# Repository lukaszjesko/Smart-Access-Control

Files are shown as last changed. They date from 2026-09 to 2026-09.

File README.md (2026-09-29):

# Smart Access Control — RFID + PIN Door Lock

Two-factor access control terminal on a custom PCB. Verification combines
something you **have** (a 13.56 MHz contactless card) with something you
**know** (a 4-digit PIN), driving an electric strike through a relay.

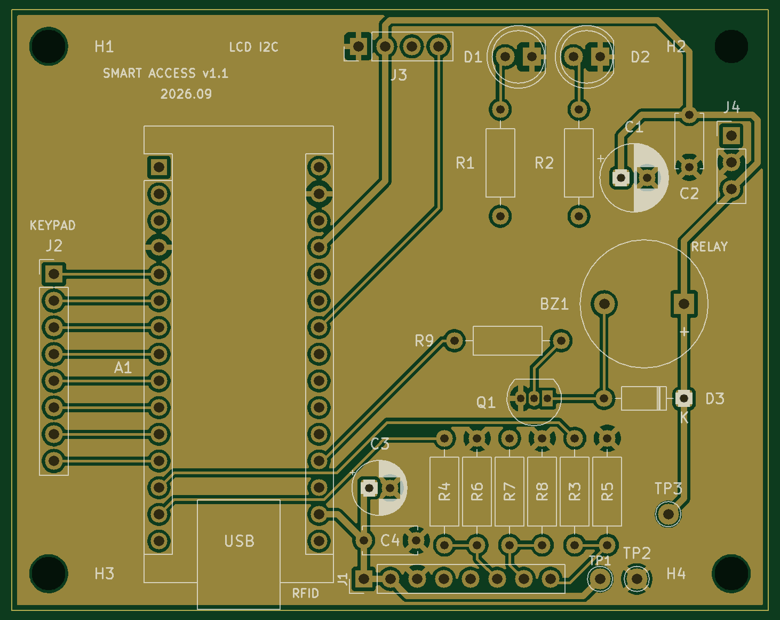
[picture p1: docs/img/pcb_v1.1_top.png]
PCB v1.1, top side


*PCB v1.1 rendered from the fabrication Gerbers. A photo of the assembled board replaces it after bring-up.*

---

## Status

| Stage | State |
|---|---|
| Firmware | Working on a breadboard |
| Schematic v1.1 | Complete, ERC clean |
| PCB v1.1 | 2-layer, 72 × 57 mm, all 28 nets routed, DRC clean |
| Fabrication | **v1.1 ordered 29 Sep 2026** (JLCPCB, 5 pcs) — files in [`fab/v1.1`](Zamek_RFID_Hardware/fab/v1.1) |
| Assembly and bring-up | Pending — boards expected mid-October |

v1.0 was never manufactured: a design review found blocking errors first.
[What the review caught](#what-the-v10-review-caught--fixed-in-v11) is the part
of this repository I would point a reviewer to first.

---

## Why this project

I wanted one device that forced me through the full hardware workflow rather
than a breadboard demo: requirements, schematic capture, footprint assignment,
layout, design rule check, manufacturing output, assembly, and bring-up.
Access control was chosen because its failure modes are interesting — a lock
that fails open is a security problem, and a lock that fails closed is a
safety problem.

---

## How it works

```
        ┌──────────────┐  SPI   ┌─────────────┐
        │  MFRC522     │◄──────►│             │
        │  RFID reader │        │             │
        └──────────────┘        │             │
                                │  ATmega328P │  GPIO   ┌────────────┐  12 V
        ┌──────────────┐  GPIO  │  (Nano)     │────────►│   Relay    │───────►
        │  4×4 keypad  │◄──────►│             │         │            │  strike
        └──────────────┘        │             │         └────────────┘
                                │             │
        ┌──────────────┐  I2C   │             │  GPIO   ┌────────────┐
        │  LCD 16×2    │◄──────►│             │────────►│ LEDs, buzz │
        └──────────────┘        └─────────────┘         └────────────┘
```

The firmware is a finite state machine with five states:

```
WAIT_FOR_CARD ──card matches──► WAIT_FOR_PIN ──► ENTERING_PIN
      ▲                                                │
      │                                    ┌───────────┴───────────┐
      │                                    ▼                       ▼
      └────────────────────────────── GRANTED                  DENIED
```

Access requires **both** factors. A valid card alone does not unlock the door.

---

## Hardware

### Pin map

| Function | Signal | Pin | Notes |
|---|---|---|---|
| RFID | SDA / SS | D10 | SPI chip select |
| RFID | MOSI | D11 | |
| RFID | MISO | D12 | |
| RFID | SCK | D13 | |
| LCD | SDA | A4 | I²C, address 0x27 |
| LCD | SCL | A5 | |
| Keypad | Rows R1–R4 | D6–D9 | |
| Keypad | Cols C1–C4 | D5–D2 | |
| Buzzer | — | A0 | |
| LED green | — | A1 | |
| LED red | — | A2 | |
| Relay | — | A3 | **Active LOW** |

### Design decisions

**Relay driven active LOW, initialised HIGH before `pinMode()`.**
During early testing the strike pulsed briefly at power-up. The relay module
is active LOW, so the pin's default state after reset released the lock for a
few milliseconds. Writing HIGH *before* configuring the pin as an output
removes the glitch. A lock that opens on every power cycle is not a lock.

**RFID reader on a connector, not on the board.**
The MFRC522 carries a tuned 13.56 MHz antenna. Putting an untuned antenna on
my own two-layer board would have meant an RF design problem I was not ready
to solve, so the module plugs into a header on a cable. That is also how a
door installation needs it: the reader outside, the controller inside.

**GND pour on both layers and a 0.6 mm power net class** to shorten return
paths for the SPI bus and give the relay switching current somewhere
low-impedance to go. Signals stay at 0.25 mm.

**The relay module switches the strike, not this board.** The strike's supply
goes to the module's own screw terminals; the board only drives its IN line.

---

## Security analysis

Honest assessment of this design. None of these are hypothetical.

| Weakness | Impact | Planned mitigation (firmware) |
|---|---|---|
| Authentication uses only the card **UID** | MIFARE Classic UIDs are readable by any phone with NFC and writable on cheap magic cards, so the card factor can be cloned in under a minute | Move to MIFARE DESFire EV3 with AES challenge–response, where the key never crosses the air interface |
| No lockout on failed PIN attempts | 4 digits is 10 000 combinations against a fixed 2 s penalty — roughly 5.5 hours of unattended guessing | Lock out after 5 attempts with exponential backoff, persisted to EEPROM so a power cycle does not reset it |
| No session timeout after a valid card | Present a card, walk away, and the terminal waits indefinitely for a PIN from anyone | 15 s timeout back to idle |
| PIN stored in plaintext in firmware | Anyone who dumps flash over ICSP reads the PIN | Store a salted hash in EEPROM; compare in constant time |
| Credentials are compile-time constants | Adding a user means reflashing | Master-card enrolment, users in EEPROM |
| MCU flash is readable | Full firmware and secrets extractable | Set the AVR lock bits |

**Not addressed by this design:** an attacker with physical access to the
*secure side* can simply bridge the relay contacts. Like most commercial
terminals, this device assumes the controller and wiring are on the protected
side of the door. Real installations put the decision logic inside and only
the reader outside — which is exactly what the OSDP protocol exists for, and
where v2 is headed.

---

## What the v1.0 review caught — fixed in v1.1

| Problem in v1.0 | Consequence | Fix in v1.1 |
|---|---|---|
| Both status LEDs wired in reverse — the MCU pin drove the cathode, the anode sat at GND | The LEDs could never light, whatever the firmware did | Polarity corrected and verified pad by pad in the board file |
| No decoupling capacitors at all | A supply dip when the relay switched, which I had masked in firmware | 100 nF + 100 µF on 5 V, 100 nF + 10 µF at the reader |
| 5 V SPI into the 3.3 V MFRC522, whose inputs are rated to VDD + 0.5 V | Inputs out of specification | 1 kΩ / 2 kΩ dividers on SS, MOSI and SCK (3.33 V); MISO direct |
| Buzzer driven straight from a GPIO | Close to the ATmega328P per-pin limit, inductive kick unclamped | BC547 driver with a 1N4148 flyback diode |
| Every net at 0.25 mm, +5 V and GND included | No margin on the power paths | `Power` net class at 0.6 mm, GND pour on both layers |
| No mounting holes | The board could not be fixed in an enclosure | 4 × M3 |
| No test points, connectors unlabelled | Hard to measure and easy to wire wrong | Test points on 3V3, 5V and GND; every connector pin labelled on the silkscreen |

## Open items

**Hardware**
- Keypad connector J2 is wired C4 C3 C2 C1 R1 R2 R3 R4, while a typical membrane
  ribbon runs R1 R2 R3 R4 C1 C2 C3 C4. To be checked on the real keypad; the fix
  belongs in `keys[][]`, not on the board.
- The reader's RST pin is tied to 3.3 V, so the MCU cannot hard-reset a hung
  reader — software reset only.

**Firmware** — unchanged since v1.0, next milestone after bring-up
- `String` on a 2 kB RAM part risks heap fragmentation — replace with a fixed
  `char` buffer.
- `delay()` inside the state machine blocks the keypad and reader for up to
  3 seconds — replace with `millis()` timing.
- No timeout after a valid card and no lockout after failed PINs (see the
  security analysis).
- No check that the reader is present at boot; an unplugged module fails
  silently.
- Successful UIDs are printed to the serial port.

---

## Repository layout

```
├── src/main.cpp                       firmware (PlatformIO, Arduino framework)
├── include/config.example.h           copy to config.h — config.h is gitignored
├── Zamek_RFID_Hardware/
│   ├── Zamek_RFID_Hardware/           KiCad 10 project: schematic and PCB
│   └── fab/v1.1/                      Gerbers, drill files and BOM sent to the fab
└── docs/
    ├── lab-notebook.md                what I did, measured and learned — failures included
    ├── zakupy_v1.1.md                 parts list for assembling v1.1
    └── img/                           renders now, photos after bring-up
```

## Build

```bash
cp include/config.example.h include/config.h   
pio run --target upload
```

Requires [PlatformIO](https://platformio.org/). Target: `nanoatmega328new`.

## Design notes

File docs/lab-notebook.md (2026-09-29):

# Lab notebook

Format: data, co robiłem, co zaobserwowałem, co z tego wynika.
Wpisuję też porażki — one są najcenniejsze.

## 2026-09-22
- Przegląd v1.0 wykazał brak kondensatorów odsprzęgających.
- Zapad napięcia przy załączaniu przekaźnika, który obszedłem
  programowo (stan HIGH), był w rzeczywistości problemem sprzętowym.
- Wniosek: problem zasilania rozwiązuje się zasilaniem, nie kodem.

## 2026-09-24

anoda dłuższa wchodzi prąd, katoda krótsza ścieta do gnd ok na stykówce ale źle na schemacie 
siatka była ustawiona 2.54 a nie 1,27 przez co nie mozna było ustwić punktów q, bo wielokrotności arduino nano to 1.27 

ceramiczny 100 nF: mała pojemność, prawie bez indukcyjności 
reaguje w nanosekundach, ale szybko się opróżnia
Od KRÓTKICH szpilek prądu — każde przełączenie układu cyfrowego
zegar Arduino 16 MHz
Przy 70 mA i spadku 0,25 V wystarcza na 0,36 µs

elektrolityczny 100 µF: 1000× większa pojemność, ale zwinięta folia
działa jak cewka reaguje wolniej.
Od DŁUŻSZYCH spadków, milisekundy załączenie przekaźnika, buzzera
Przy 70 mA i spadku 0,25 V wystarcza na 0,36 ms

Dlatego dajemy oba: ceramik łapie szybkie, elektrolit długie.
Ceramik jak najbliżej pinu zasilania — każdy mm ścieżki to dodatkowa indukcyjność.

podłączenie buzzera do bazy tranzysotra, strzałka na tranzystorze - emiter, dida do wciągania prądu który cofa się z cewki buzzera, 

jeśłi zasilanie to ścieżka 0.6 mm, zwykły sygnał to cienka ścieżka - opisanie klas 
tworzenie klasy - clearance - odstęp od innych wierszy, 

"pierścieniem" (annular ring) - przelotka 0.6 mm wiertło 0.4 mm - zostaje po 0.1 mm, rozwiązanie - zmniejszenie wiertła 

przy wylewce na spodzie siatka na 0.5mm - strefa 0.5 wewnątrz krawędzi 
clearance 0.3 zamiast 0.2 - wylewka dlaje od ścieżek, mniejsze ryzyko mostka cyny, 
pad connnections - thermal relief, 

przy gerberach zaznaczyć - subtract soldermask from silkscreen - farba nie wejdzie na pady
Use Protel filename - końcówki które firmy rozpoznają automatycznie, po zaznaczeniu - plot
-PTH.drl plik - pady, otwory metalizowane, -NPTH.drl - 4 otwory montażowe, niemetalizowane
BOM -> edytor schematu -> Tools -> Generate Bill of Materials → CSV do tego pliku - > export 

NPTH = 4x M3 mounting
holes - osobne pliki wierceń metalizowanych i niemetalizowanych (NPTH to
4 otwory M3)

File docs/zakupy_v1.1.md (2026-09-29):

# Zakupy — Smart Access v1.1

Sprawdzone 2026-09-29 z datasheetami i footprintami płytki.
Stan magazynu sprawdź w koszyku — strona TME czasem pokazuje „0”, mimo że towar jest.

## Do kupienia — TME (jedno zamówienie)

| Na płytce | Co | Symbol TME | Ile | Dlaczego ten |
|---|---|---|---|---|
| C1 | 100 µF 25 V, Ø6,3 mm, rozstaw 2,5 mm | [ECA1EM101](https://www.tme.eu/pl/details/eca1em101/kondensatory-elektrolityczne-tht/panasonic/) | 2 | wymiary = footprint; 25 V zamiast 16 V jest OK (to maksimum, zapas nie szkodzi) |
| C3 | 10 µF 16 V, Ø5 mm, rozstaw 2,0 mm | [ECA1CM100](https://www.tme.eu/pl/details/eca1cm100/kondensatory-elektrolityczne-tht/panasonic/) | 2 | wymiary = footprint |
| Q1 | BC547B | [BC547B-DIO](https://www.tme.eu/pl/details/bc547b-dio/tranzystory-npn-tht/diotec-semiconductor/bc547b/) | 3 | nóżki 1=C 2=B 3=E, tak samo jak na schemacie |
| D3 | 1N4148 | [1N4148-DIO](https://www.tme.eu/pl/details/1n4148-dio/diody-uniwersalne-tht/diotec-semiconductor/1n4148/) | 3 | pomiń, jeśli masz w zestawie |
| R5, R6, R8 | rezystor 2 kΩ 1% | [MF0207FTE-2K](https://www.tme.eu/pl/details/mf0207fte-2k/rezystory-metalizowane-tht-06w/yageo/mf0207fte52-2k/) | 5 | od 1 szt.; tańsze węglowe 2k są wyprzedane |
| R1 | rezystor 300 Ω 1% | [MF0207FTE-300R](https://www.tme.eu/pl/details/mf0207fte-300r/rezystory-metalizowane-tht-06w/yageo/mf0207fte52-300r/) | 2 | od 1 szt. |

Zapasowy kondensator do C3, gdyby ECA1CM100 był niedostępny: dowolny 10 µF, 16–35 V,
**Ø5 mm**, rozstaw 2,0 mm albo 2,5 mm (ECA1CM100I; nóżki lekko ścisnąć do 2 mm).

## Do kupienia — Botland

| Co | Link | Ile |
|---|---|---|
| Zestaw nylonowych śrub i dystansów M3 (otwory montażowe H1–H4) | [Botland](https://botland.com.pl/srubki-i-nakretki/13577-zestaw-nylonowych-srubek-i-podkladek-dystansowych-m3-180-elementow-5904422320973.html) | 1 |
| Kable dupont żeńsko-żeńskie (tylko jeśli nie masz) | wyszukaj „przewody połączeniowe żeńsko-żeńskie” | 1 paczka |

## Płytki PCB

JLCPCB albo PCBWay, 5 szt. Pliki: `Zamek_RFID_Hardware/fab/v1.1/`.
Zamawiasz **po** sprawdzeniu footprintów z częściami w ręku.

## Już masz

| Na płytce | Co | Status |
|---|---|---|
| J1–J4 | goldpin męski 1x40 | OK |
| podstawka Nano | goldpin żeński 1x40 → 2×15 | OK |
| C2, C4 | 100 nF | sprawdź rozstaw nóżek: płytka ma 5 mm |
| R3, R4, R7, R9 | 1 kΩ z zestawu | OK |
| R2 | 200 Ω z zestawu | OK |
| D1, D2 | LED czerwona i zielona z zestawu | OK |
| BZ1 | buzzer HCM1206X | OK: Ø12×9,5 mm, rozstaw 7,6 mm = footprint; 6 V znamionowo, działa od 4 V |
| — | ARK KF301 | nie pasują do płytki, zapas |
| — | 2,2 kΩ z zestawu | **nie używać zamiast 2k** |

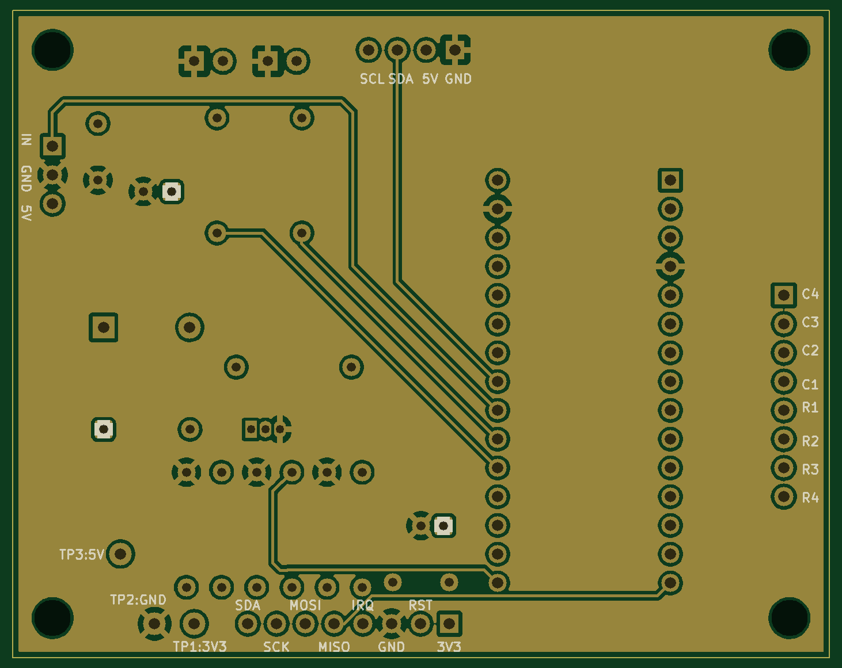
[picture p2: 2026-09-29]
docs/img/pcb_v1.1_bottom.png

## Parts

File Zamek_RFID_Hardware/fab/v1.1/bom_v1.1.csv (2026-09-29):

Reference | Value | Datasheet | Footprint | Qty | DNP
A1 | Arduino_Nano_v3.x | http://www.mouser.com/pdfdocs/Gravitech_Arduino_Nano3_0.pdf | Module:Arduino_Nano | 1
BZ1 | Buzzer |  | Buzzer_Beeper:Buzzer_12x9.5RM7.6 | 1
C1 | 100uF 16V |  | Capacitor_THT:CP_Radial_D6.3mm_P2.50mm | 1
C2,C4 | 100nF |  | Capacitor_THT:C_Disc_D5.0mm_W2.5mm_P5.00mm | 2
C3 | 10uF 16V |  | Capacitor_THT:CP_Radial_D5.0mm_P2.00mm | 1
D1 | LED red 5mm |  | LED_THT:LED_D5.0mm | 1
D2 | LED green 5mm |  | LED_THT:LED_D5.0mm | 1
D3 | 1N4148 | https://assets.nexperia.com/documents/data-sheet/1N4148_1N4448.pdf | Diode_THT:D_DO-35_SOD27_P7.62mm_Horizontal | 1
J1,J2 | Conn_01x08 |  | Connector_PinHeader_2.54mm:PinHeader_1x08_P2.54mm_Vertical | 2
J3 | Conn_01x04 |  | Connector_PinHeader_2.54mm:PinHeader_1x04_P2.54mm_Vertical | 1
J4 | Conn_01x03 |  | Connector_PinHeader_2.54mm:PinHeader_1x03_P2.54mm_Vertical | 1
Q1 | BC547 | https://www.onsemi.com/pub/Collateral/BC550-D.pdf | Package_TO_SOT_THT:TO-92_Inline | 1
R1 | 300 |  | Resistor_THT:R_Axial_DIN0207_L6.3mm_D2.5mm_P10.16mm_Horizontal | 1
R2 | 200 |  | Resistor_THT:R_Axial_DIN0207_L6.3mm_D2.5mm_P10.16mm_Horizontal | 1
R3,R4,R7,R9 | 1k |  | Resistor_THT:R_Axial_DIN0207_L6.3mm_D2.5mm_P10.16mm_Horizontal | 4
R5,R6,R8 | 2k |  | Resistor_THT:R_Axial_DIN0207_L6.3mm_D2.5mm_P10.16mm_Horizontal | 3

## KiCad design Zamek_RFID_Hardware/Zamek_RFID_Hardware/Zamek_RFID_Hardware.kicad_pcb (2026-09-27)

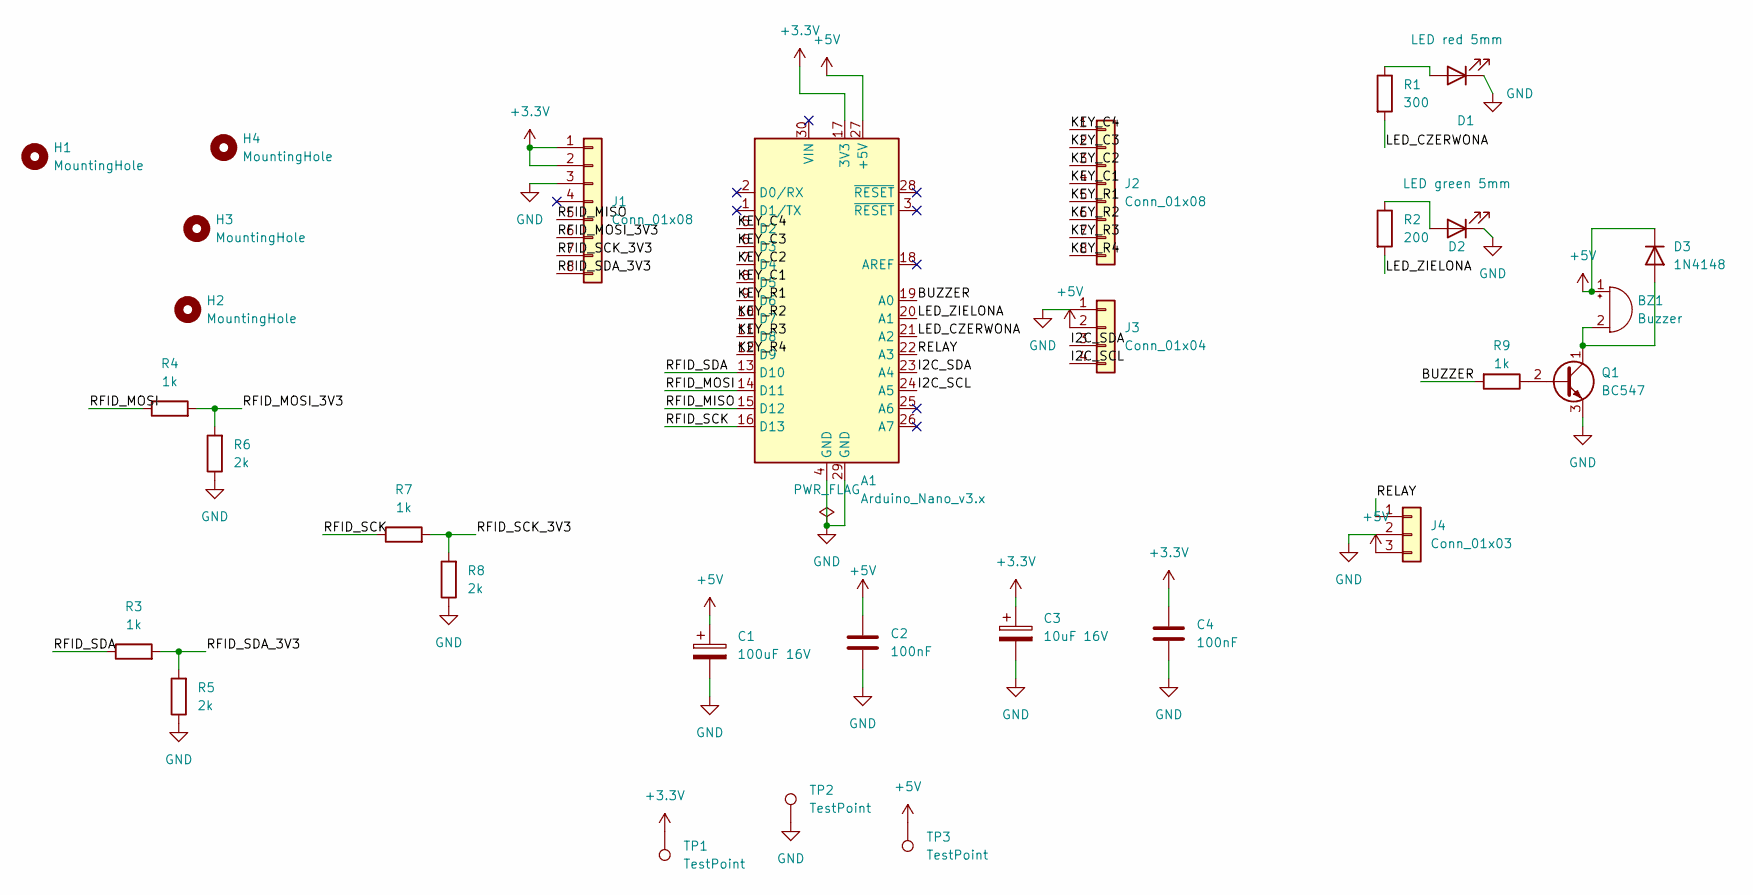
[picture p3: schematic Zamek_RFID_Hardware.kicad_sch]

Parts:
A1: Arduino_Nano_v3.x; Arduino_Nano
BZ1: Buzzer; Buzzer_12x9.5RM7.6
C1: 100uF 16V; CP_Radial_D6.3mm_P2.50mm
C2, C4: 100nF; C_Disc_D5.0mm_W2.5mm_P5.00mm
C3: 10uF 16V; CP_Radial_D5.0mm_P2.00mm
D1: LED red 5mm; LED_D5.0mm
D2: LED green 5mm; LED_D5.0mm
D3: 1N4148; D_DO-35_SOD27_P7.62mm_Horizontal
H1, H2, H3, H4: MountingHole; MountingHole_3.2mm_M3
J1, J2: Conn_01x08; PinHeader_1x08_P2.54mm_Vertical
J3: Conn_01x04; PinHeader_1x04_P2.54mm_Vertical
J4: Conn_01x03; PinHeader_1x03_P2.54mm_Vertical
Q1: BC547; TO-92_Inline
R1: 300; R_Axial_DIN0207_L6.3mm_D2.5mm_P10.16mm_Horizontal
R2: 200; R_Axial_DIN0207_L6.3mm_D2.5mm_P10.16mm_Horizontal
R3, R4, R7, R9: 1k; R_Axial_DIN0207_L6.3mm_D2.5mm_P10.16mm_Horizontal
R5, R6, R8: 2k; R_Axial_DIN0207_L6.3mm_D2.5mm_P10.16mm_Horizontal
TP1, TP2, TP3: TestPoint; TestPoint_THTPad_D2.0mm_Drill1.0mm

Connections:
+3.3V: A1.17 (3V3), C3.1, C4.1, J1.1, J1.2, TP1.1 (1_1)
+5V: A1.27 (+5V), BZ1.1 (+), C1.1, C2.1, D3.1 (K), J3.2, J4.3, TP3.1 (1_1)
/BUZZER: A1.19 (A0), R9.2
/I2C_SCL: A1.24 (A5), J3.4
/I2C_SDA: A1.23 (A4), J3.3
/KEY_C1: A1.8 (D5), J2.4
/KEY_C2: A1.7 (D4), J2.3
/KEY_C3: A1.6 (D3), J2.2
/KEY_C4: A1.5 (D2), J2.1
/KEY_R1: A1.9 (D6), J2.5
/KEY_R2: A1.10 (D7), J2.6
/KEY_R3: A1.11 (D8), J2.7
/KEY_R4: A1.12 (D9), J2.8
/LED_CZERWONA: A1.21 (A2), R1.2
/LED_ZIELONA: A1.20 (A1), R2.2
/RELAY: A1.22 (A3), J4.1
/RFID_MISO: A1.15 (D12), J1.5
/RFID_MOSI: A1.14 (D11), R4.1
/RFID_MOSI_3V3: J1.6, R4.2, R6.2
/RFID_SCK: A1.16 (D13), R7.1
/RFID_SCK_3V3: J1.7, R7.2, R8.2
/RFID_SDA: A1.13 (D10), R3.1
/RFID_SDA_3V3: J1.8, R3.2, R5.2
GND: A1.4 (GND), A1.29 (GND), C1.2, C2.2, C3.2, C4.2, D1.1 (K), D2.1 (K), J1.3, J3.1, J4.2, Q1.3 (E), R5.1, R6.1, R8.1, TP2.1 (1_1)
unnamed: BZ1.2 (-), D3.2 (A), Q1.1 (C)
unnamed: D1.2 (A), R1.1
unnamed: D2.2 (A), R2.1
unnamed: Q1.2 (B), R9.1

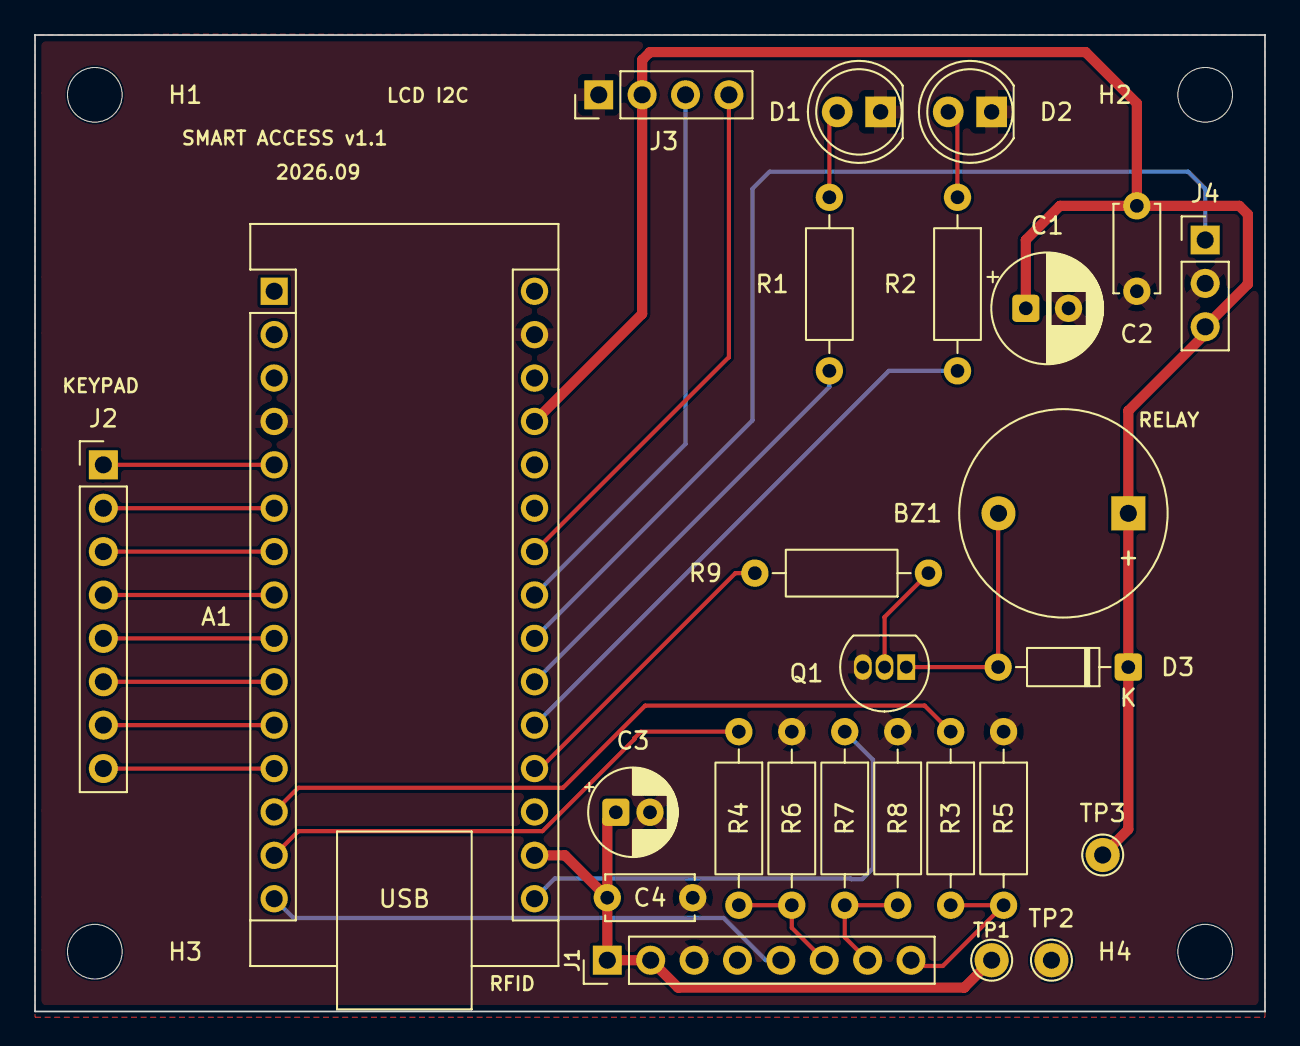
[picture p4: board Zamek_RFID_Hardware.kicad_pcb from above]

Board: 2 copper layers, 72.0 x 57.2 mm, 30 parts (0 on the bottom side), 28 nets.

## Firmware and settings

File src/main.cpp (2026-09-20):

#include <Arduino.h>
#include <Wire.h>
#include <Keypad.h>
#include <LiquidCrystal_I2C.h>
#include <SPI.h>
#include <MFRC522.h>
#include "config.h"

#define SDA_PIN 10
#define RST_PIN -1

MFRC522 rfid(SDA_PIN, RST_PIN);
LiquidCrystal_I2C lcd(0x27, 16, 2); 


const byte ROWS = 4; 
const byte COLS = 4;

byte rowPins[ROWS] = {6,7,8,9};
byte colPins[COLS] = {5,4,3,2};

char keys[ROWS][COLS] = {
 {'1','2','3','A'},
 {'4','5','6','B'},
 {'7','8','9','C'},
 {'*','0','#','D'}
 };

 enum StanSystemu {
    CZEKAM_NA_PIN,
    WPISYWANIE_PINU,
    ZAAKCEPTOWANY,
    ODRZUCONY,
    CZEKAM_NA_KARTE
 };

 StanSystemu obecnyStan = CZEKAM_NA_KARTE;


 String wpisanyPin = "";
 const byte PIN_BUZZER = A0;
 const byte PIN_LED_ZIELONA = A1;
 const byte PIN_LED_CZERWONA = A2;
 const byte PIN_PRZEKAZNIK = A3;


 
 Keypad keypad = Keypad(makeKeymap(keys), rowPins, colPins, ROWS, COLS);

void pokazLinie(byte wiersz, const char* tekst) {
  lcd.setCursor(0, wiersz);
  lcd.print("                "); 
  lcd.setCursor(0, wiersz);
  lcd.print(tekst);
}

void setup() {
  
  pinMode(PIN_BUZZER, OUTPUT);
  pinMode(PIN_LED_ZIELONA, OUTPUT);
  pinMode(PIN_LED_CZERWONA, OUTPUT);
  pinMode(PIN_PRZEKAZNIK, OUTPUT);

  digitalWrite(PIN_PRZEKAZNIK, HIGH);
  digitalWrite(PIN_BUZZER, LOW);
  digitalWrite(PIN_LED_CZERWONA, HIGH);
  digitalWrite(PIN_LED_ZIELONA, LOW);

  SPI.begin();
  rfid.PCD_Init();
  Serial.begin(115200);

  lcd.init();
  lcd.backlight();
  lcd.setCursor(0, 0);
  lcd.print("System gotowy");
  lcd.setCursor(0, 1);
  lcd.print("Zbliz karte: ");
}

void loop() {
  char key = keypad.getKey();
  
  switch(obecnyStan){
    case CZEKAM_NA_PIN:
      if (key){
        wpisanyPin+= key;
        lcd.clear();
        lcd.setCursor(0, 0);
        lcd.print("Wprowadz PIN:");
        lcd.setCursor(0, 1);
        lcd.print("*");
        obecnyStan = WPISYWANIE_PINU;

      }
    break;

    case WPISYWANIE_PINU:
      if(key){
        wpisanyPin += key;
        lcd.print("*");

        if (wpisanyPin.length() == 4){
          lcd.clear();
          lcd.setCursor(0, 0);
          lcd.print("Weryfikacja...");

          if (wpisanyPin == tajnyPin){
            obecnyStan = ZAAKCEPTOWANY;
          }else{
            obecnyStan = ODRZUCONY;
          }
        
        }
      }
    break;

    case CZEKAM_NA_KARTE:
      
      if (rfid.PICC_IsNewCardPresent() && rfid.PICC_ReadCardSerial()) {      
        String odczytaneUID = "";
        for (byte i = 0; i < rfid.uid.size; i++) {         
          odczytaneUID.concat(String(rfid.uid.uidByte[i] < 0x10 ? " 0" : " "));
          odczytaneUID.concat(String(rfid.uid.uidByte[i], HEX));
        }
        odczytaneUID.toUpperCase(); 
        if (odczytaneUID == dozwolonaKarta) { 
          
        Serial.println(odczytaneUID);

        rfid.PICC_HaltA();
        digitalWrite(PIN_BUZZER, HIGH); delay(100); digitalWrite(PIN_BUZZER, LOW); 
        lcd.clear();
        lcd.setCursor(0, 0);
        lcd.print("Karta OK");
        lcd.setCursor(0, 1);
        lcd.print("Wprowadz PIN:");
        obecnyStan = CZEKAM_NA_PIN; 
      }
      else{
        Serial.println("Nieznana karta: " + odczytaneUID);
        rfid.PICC_HaltA();
        lcd.clear();
        lcd.setCursor(0, 0);
        lcd.print("Odmowa dostepu");
        lcd.setCursor(0, 1);
        lcd.print("Nieznana karta");

        digitalWrite(PIN_BUZZER, HIGH);
        delay(2000);
        digitalWrite(PIN_BUZZER, LOW);

        lcd.clear();
        lcd.setCursor(0, 0);
        lcd.print("System gotowy");
        lcd.setCursor(0, 1);
        lcd.print("Zbliz karte: ");
        
      }
    }
    break;

    case ZAAKCEPTOWANY:
      lcd.clear();
      lcd.setCursor(0, 0);
      lcd.print("Dostep przyznany"); 
      lcd.setCursor(0, 1);
      lcd.print("Zamek otwarty");
      
      digitalWrite(PIN_LED_CZERWONA, LOW);
      digitalWrite(PIN_LED_ZIELONA, HIGH);
      digitalWrite(PIN_PRZEKAZNIK, LOW);
      delay(3000);
      digitalWrite(PIN_PRZEKAZNIK, HIGH);
      digitalWrite(PIN_LED_ZIELONA, LOW);
      digitalWrite(PIN_LED_CZERWONA, HIGH);
      
      lcd.clear();
      lcd.setCursor(0, 0);
      lcd.print("System gotowy");
      lcd.setCursor(0, 1);
      lcd.print("Zbliz karte: ");

      wpisanyPin = "";
      obecnyStan = CZEKAM_NA_KARTE;
    break;

    case ODRZUCONY:
      lcd.clear();
      lcd.setCursor(0, 0);
      lcd.print("Odmowa dostepu!");
      lcd.setCursor(0, 1);
      lcd.print("Bledny PIN!");
      
      digitalWrite(PIN_BUZZER, HIGH);
      delay(2000);
      digitalWrite(PIN_BUZZER, LOW);
      
      lcd.clear();
      lcd.setCursor(0, 0);
      lcd.print("System gotowy");
      lcd.setCursor(0, 1);
      lcd.print("Zbliz karte: ");
      
      wpisanyPin = "";
      obecnyStan = CZEKAM_NA_KARTE;
    break;
  }
}

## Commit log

2026-08-17 wyrzucenie wyświetlacza, rozwiązanie problemu pada, dodanie enum i kontroli wpisywania pinu
    [main.cpp]
2026-08-17 dodanie buzzera i ledów
    [main.cpp]
2026-08-18 zamiana z servo na zamek
2026-08-20 Migracja: Dodanie projektu PCB (Hardware) do repozytorium z kodem
    [Zamek_RFID_Hardware.kicad_pcb, Zamek_RFID_Hardware.kicad_sch]
2026-08-20 Revise README
    Updated project description, current status, and hardware connections in README.
2026-08-22 przydzielanie footprintów
    [Zamek_RFID_Hardware.kicad_sch]
2026-08-22 Projekt PCB: Ułożenie elementów i narysowanie krawędzi płytki (Widok 3D)
    [Zamek_RFID_Hardware.kicad_pcb, Zamek_RFID_Hardware.kicad_sch]
2026-08-23 poprawki i wylewka
    [Zamek_RFID_Hardware.kicad_pcb, Zamek_RFID_Hardware.kicad_sch]
2026-09-02 dodanie plików gerber
    [Zamek_RFID_Hardware-B_Cu.gbr, Zamek_RFID_Hardware-B_Mask.gbr, Zamek_RFID_Hardware-B_Paste.gbr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]
2026-09-24 hw: schematic v1.1 - fix LED polarity, add decoupling, SPI level shifting and buzzer driver
    - Rotate D1/D2 so the GPIO drives the anode through the resistor;
    PCB footprints rotated 180 deg in place, existing copper reused
    - R1 = 300 R, R2 = 200 R (10 mA per LED)
    - Add 100 uF + 100 nF on +5V at the relay connector and
    10 uF + 100 nF on +3.3V at the RC522 connector
    - Add 1k/2k dividers on SS, MOSI and SCK: MFRC522 inputs are limited
    to VDD + 0.5 V; MISO stays direct (3.3 V is above ATmega328P VIH)
    - Drive the buzzer through a BC547 with a 1N4148 flyback diode
    - Add test points on +5V, +3.3V and GND, and four M3 mounting holes
    - Rename net PRZEKAZNIK to RELAY (ASCII only for CAM tools)
    -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
    [Zamek_RFID_Hardware.kicad_pcb, Zamek_RFID_Hardware.kicad_sch]
2026-09-24 docs: record v1.1 schematic status and working notes
    - CLAUDE.md: current project stage, next step (PCB update) and the
    remaining v1.1 plan
    - lab notebook: LED polarity analysis and ERC findings
    - .gitignore: remove comments
2026-09-24 after F8 and cleaning
    [Zamek_RFID_Hardware.kicad_pcb]
2026-09-25 docs: update pcb v1.1 progress notes
    [Zamek_RFID_Hardware.kicad_pcb]
2026-09-27 F8 and the first tracks
    [Zamek_RFID_Hardware.kicad_pcb]
2026-09-27 hw: route all signal and power nets
    - Power on F.Cu with 0.6 mm tracks, decoupling caps placed in the current path
    - Keypad: 8 straight parallel tracks
    - Crossing nets (SDA, RELAY, LEDs, SCK, MISO) on B.Cu, no vias
    - SPI routed under the Nano between header pins
    - GND left for copper pour
    [Zamek_RFID_Hardware.kicad_pcb]
2026-09-27 hw: add GND pours on both layers
    - thermal reliefs, islands removed
    [Zamek_RFID_Hardware.kicad_pcb]
2026-09-27 hw: add silkscreen
    - board name, version, connector and pin labels
    [Zamek_RFID_Hardware.kicad_pcb]
2026-09-27 chore: remove v1.0 Gerber files, stop tracking KiCad history
    - outdated v1.0 Gerbers must not be sent to the manufacturer
    [Zamek_RFID_Hardware-B_Cu.gbr, Zamek_RFID_Hardware-B_Mask.gbr, Zamek_RFID_Hardware-B_Paste.gbr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]
2026-09-27 hw: fix R6 value notation (2K - 2k)
    - consistent with R5/R8, so BOM groups all 2k resistors in one line
    - lowercase k is the SI prefix
    [Zamek_RFID_Hardware.kicad_pcb, Zamek_RFID_Hardware.kicad_sch]
2026-09-27 docs: error in capacitor descriptions
2026-09-27 hw: add v1.1 fabrication outputs
    -Gerbers for 7 layers with Protel extensions, no paste layers
    -separate PTH and NPTH drill files (NPTH = 4x M3 mounting
    holes)
    -BOM exported from KiCad
    -generated after ERC, DRC and schematic parity check with 0
    errors
    [Zamek_RFID_Hardware-B_Cu.gbl, Zamek_RFID_Hardware-B_Mask.gbs, Zamek_RFID_Hardware-B_Silkscreen.gbo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]
2026-09-29 hw: exclude test points from BOM
    [Zamek_RFID_Hardware.kicad_sch, bom_v1.1.csv]
2026-09-29 docs: README v1.1 ordered, review findings, PCB renders
2026-10-09 docs: rewrite README, add schematic PDF
2026-10-13 hw: add Arduino Nano 3D model
2026-10-18 hw: set R2 to 300 ohm, tidy up schematic labels and title block
2026-10-18 docs: add board photos, schematic and PCB layout to README
2026-10-18 docs: notebook: assembly and relay supply problem
2026-10-18 docs: add schematic image, update schematic PDF
2026-10-18 hw: set schematic revision in project file
